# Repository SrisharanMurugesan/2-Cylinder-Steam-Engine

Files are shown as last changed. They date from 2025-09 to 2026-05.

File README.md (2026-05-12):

# 2-Cylinder-Steam-Engine
<p align="center">
  A - Front CAD view
  B - Isometric CAD view
</p>

<p align="center">
  C - Full CAD assembly view
</p>

## Description

A fully engineered, 2-cylinder vertical steam engine designed for assembly.  
This project includes complete CAD models, 3D-printable components, and hardware specs for a working demonstration engine with a shared crankshaft, crosshead guides, and a flywheel mounted on a wooden base.

The design uses standard fasteners and realistic tolerances so that, once printed and cleaned up, the parts assemble with minimal adjustment.

---

### Mechanical Overview

- **Configuration:** Twin vertical cylinders driven by a common crankshaft and flywheel  
- **Structure:** Printed crankcase/block with bolt-on cylinder heads and bearing caps  
- **Motion system:** Pistons → connecting rods → crank → flywheel  
- **Guidance:** Vertical guide rods keep piston rods in pure linear motion  
- **Base:** Wood base plate with mounting points for the engine frame and flywheel bearings  

---

### Tolerances and Fits

The CAD is modeled with 3D-printing realities in mind:

- **Shafts & holes (running fits)**  
  - Shaft diameters: typically 4–6 mm (metal rod recommended)  
  - Printed bearing bores: +0.10 to +0.20 mm over shaft diameter (e.g., 6.10–6.20 mm for a 6 mm shaft)  
- **Fastener holes**  
  - Through holes: +0.20–0.30 mm over screw diameter  
  - Clearance for nuts and heads modeled with +0.20 mm all around  
- **Press-fit features (pins, dowels)**  
  - Undersize the *hole* relative to pin size, then drill to final size as needed  

(If your printer is calibrated and precise, you can tighten these marginal numbers; else use clearances of another 0.05–0.10 mm.)

---

### Recommended Materials

- **Structural parts (block, cylinder, crosshead guides, flywheel):**  
  - PLA+ or PETG  
- **Frictional components (Subject to high friction and constant motion):**  
  - PETG or nylon preferred; PLA will work for demo use  
- **Shafts & pins:**  
  - Steel or brass rod stock (not printed) for better strength and wear

---

### Bambu Lab A1 Print Specs

Optimized slicing settings:

- **Nozzle:** 0.4 mm  
- **Layer height:** 0.16–0.20 mm  
- **Walls/perimeters:** 4  
- **Top/bottom layers:** 6–8  
- **Infill:**
  - Structural parts (block, flywheel, bearing supports): 35–45% gyroid or cubic  
  - Cosmetic/small brackets: 20–25%  
- **Speed:** use A1 “Standard”
- **Supports:**  
  - On build plate only where possible (Supports autogenerated by software will suffice)  
  - Flywheel: printed flat with support only under inner ring if necessary  
- **Brim:** 5–8 mm brim on tall, slender parts (guides, columns)

---

### Notes on Assembly

- Lightly sand all sliding and rotating interfaces.  
- Re-drill critical bores (piston rod guides, main bearing bores, crank pin holes) to their final size.  
- Dry-fit the crankshaft, flywheel, and rods first to ensure rotation before tightening fasteners.  
- A tiny amount of grease or lube on shafts and crossheads will reduce friction significantly.

---

### Authors Note

This steam engine was designed from an old compilation of drawing sheets, which were modeled in SolidWorks to created this engine. I used this engine as a learning marker to learn the fundamentals of automobile design and better develop my skills with SolidWork assemblies. I 3d printed this engine on my Bambu Lab A1 to understand the manufacturing constraints of translating high precision parts into real world products and it currently sits as decoration in my room. I hope you enjoy!

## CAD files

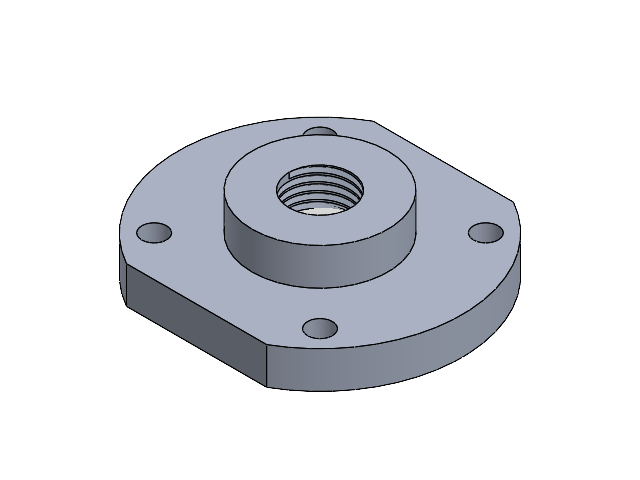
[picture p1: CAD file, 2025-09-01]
SubAssembly/Top Crank.SLDASM
MC2403773CT-001
MC2403774CT-001
MC2403775CT-001

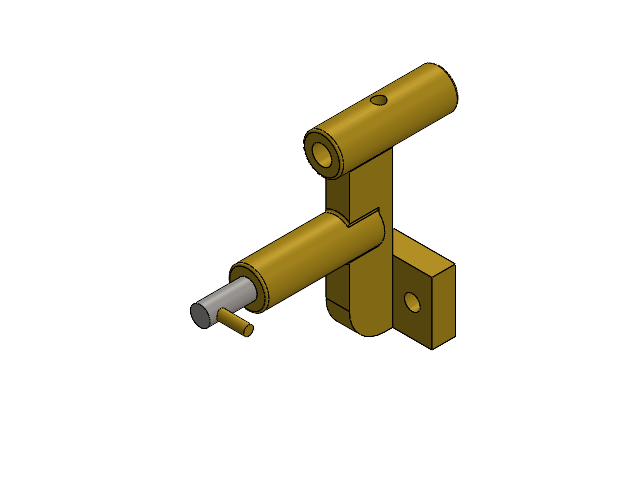
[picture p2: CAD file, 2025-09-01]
SubAssembly/Top Connector.SLDASM
MC2403781CT-001
MC2403782CT-001
MC2403783CT-001

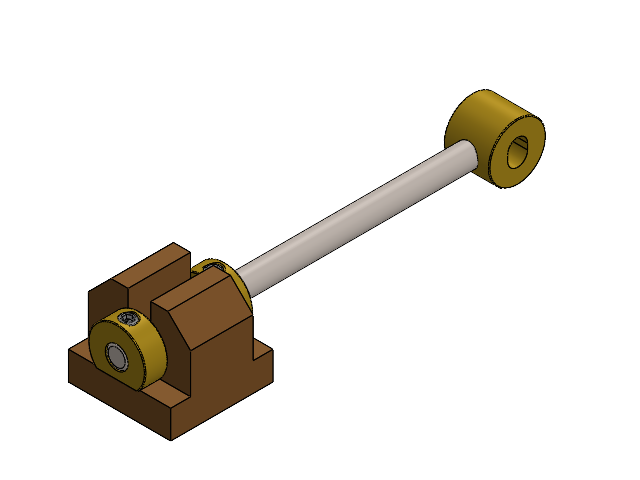
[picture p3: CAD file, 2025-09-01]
SubAssembly/Sub-Assembly4.SLDASM
MC2403729CT-001
MC2403760CT-001
MC2403761CT-001
MC2403731CT-001 x 2

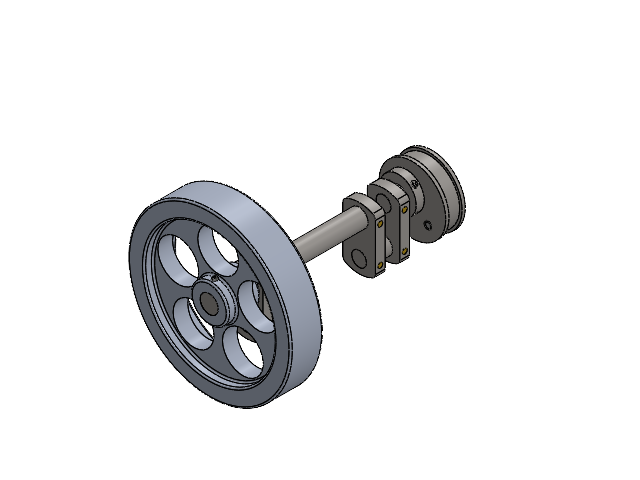
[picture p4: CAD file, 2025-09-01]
SubAssembly/SubAssembly 1.SLDASM
MC2403720CT-001
MC2403758CT-001
MC2403759CT-001
COTS - SCREW R-HEAD A-KEY M4.7X12 92095A192
MC2403724CT-001 x 4
MC2403722CT-001
MC2403723CT-001 x 2
MC2403845CT-001 x 8
MC2403721CT-001 x 2
COTS - SET SCREW M3.0X0.5X6.0 92015A104

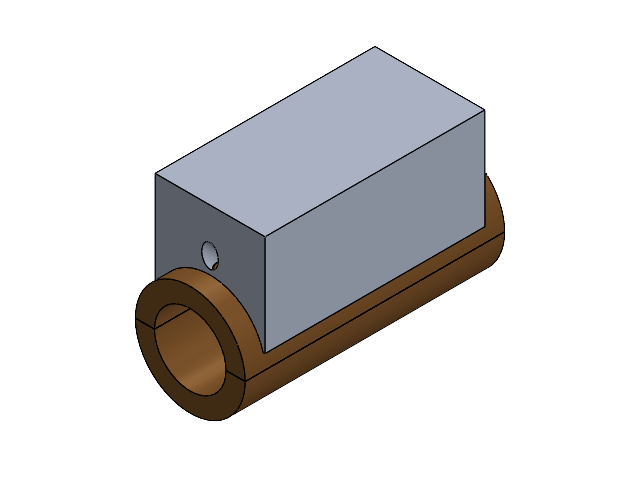
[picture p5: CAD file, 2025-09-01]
SubAssembly/SubAssembly Beginning.SLDASM
MC2403798CT-001
MC2403799CT-001
MC2403800CT-001
MC2403801CT-001

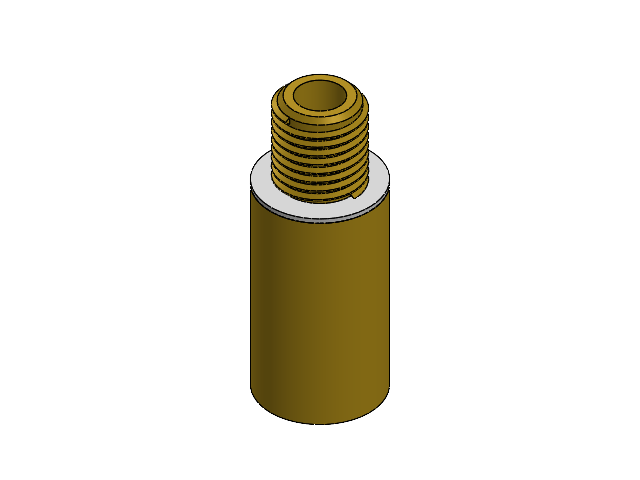
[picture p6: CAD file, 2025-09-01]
SubAssembly/Piston.SLDASM
MC2403771CT-001
MC2403772CT-001

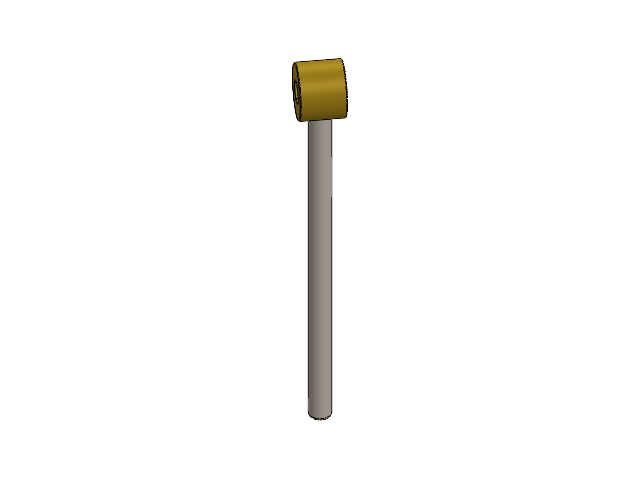
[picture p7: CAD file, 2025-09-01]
SubAssembly/Piston Pipe.SLDASM
MC2403760CT-001
MC2403761CT-001

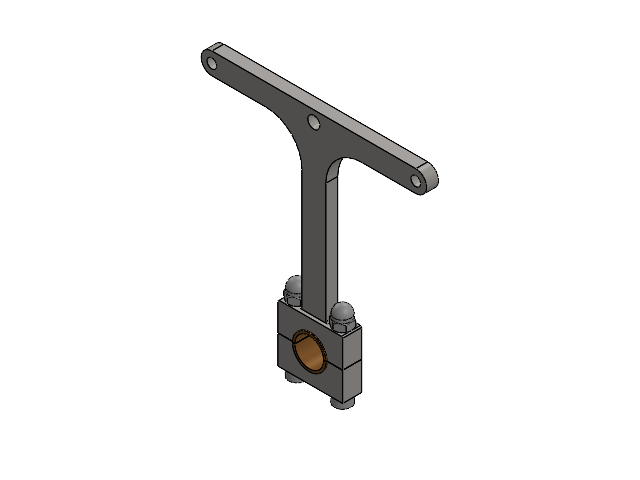
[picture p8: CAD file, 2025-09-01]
SubAssembly/Pipes Connected.SLDASM
MC2403734CT-001
MC2403787CT-001
MC2403849CT-001 x 2

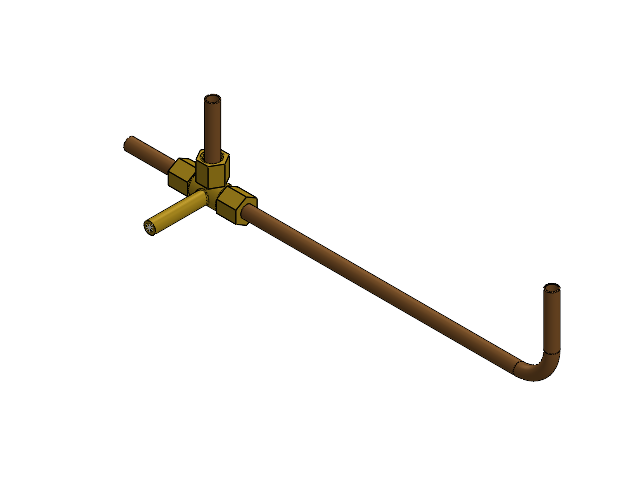
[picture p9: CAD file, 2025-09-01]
SubAssembly/Pipes Beginning.SLDASM
MC2403805CT-001
MC2403806CT-001 x 2
MC2403807CT-001
MC2403784CT-001 x 3
MC2403785CT-001 x 3

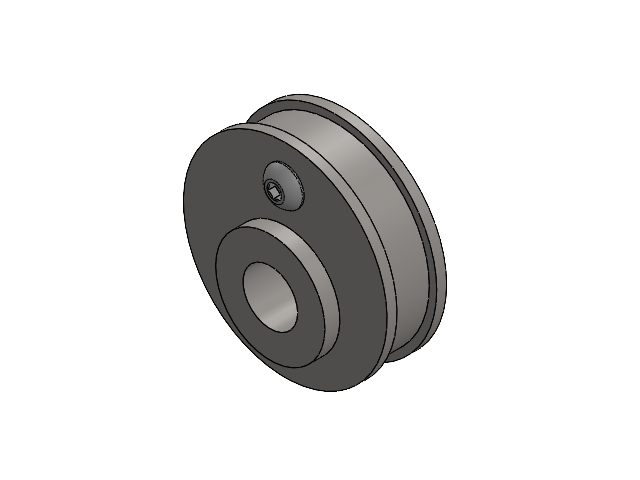
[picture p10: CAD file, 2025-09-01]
SubAssembly/Main Base.SLDASM
MC2403758CT-001
MC2403759CT-001

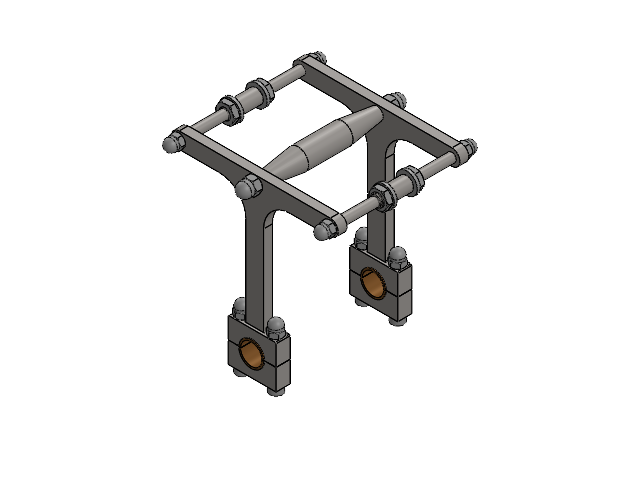
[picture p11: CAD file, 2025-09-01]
SubAssembly/Almost Completed.SLDASM
MC2403735CT-001
MC2403736CT-001 x 2
90326A201_Steel Thin Hex Nut x 4
96505A114_Steel Oversized Washer x 4

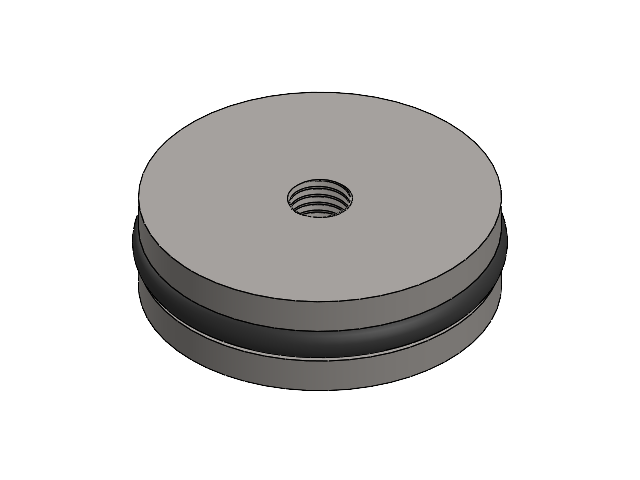
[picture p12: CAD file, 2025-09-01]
SubAssembly/FlyWheel.SLDASM
MC2403786CT-001
COTS - O-RING SILICONE HI TEMP 5233T816

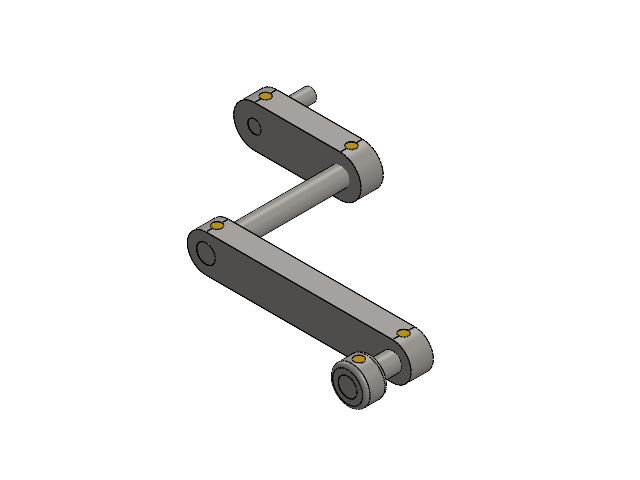
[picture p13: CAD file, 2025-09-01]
SubAssembly/Crank.SLDASM
MC2403762CT-001
MC2403763CT-001
MC2403764CT-001
MC2403716CT-001 x 5
MC2403766CT-001
MC2403767CT-001
MC2403840CT-001

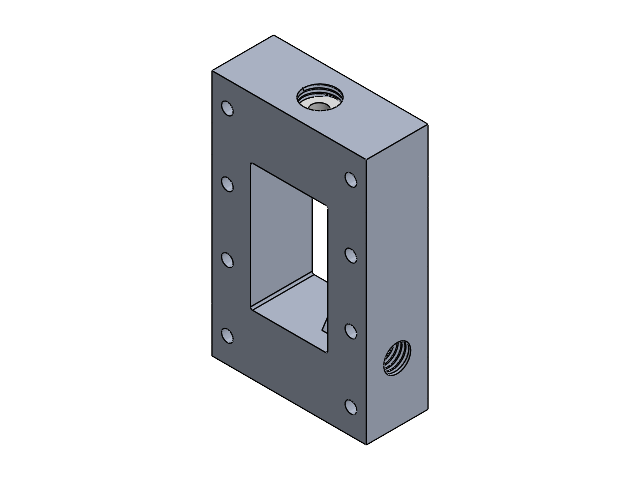
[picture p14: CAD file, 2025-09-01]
SubAssembly/Crank Shaft.SLDASM
MC2403778CT-001
MC2403779CT-001
MC2403780CT-001

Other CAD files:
SubAssembly/Piston Connector.SLDASM
SubAssembly/All pipes connected.SLDASM
SubAssembly/Connected Cranks.SLDASM
SubAssembly/Pipe Conmnector Assembly.SLDASM
Parts/Axel (2).SLDPRT
Parts/Axel (3).SLDPRT
Parts/Axel (4).SLDPRT
Parts/Axel (5).SLDPRT
Parts/Axel (6).SLDPRT
Parts/Axel (7).SLDPRT
Parts/Axel Bridge.SLDPRT
Parts/Axel.SLDPRT
Parts/Base (2).SLDPRT
Parts/Base Join.SLDPRT
Parts/Base Plate (2).SLDPRT
Parts/Base Plate.SLDPRT
Parts/Base.SLDPRT
Parts/Bottom Cover.SLDPRT
Parts/Brass (2).SLDPRT
Parts/Brass .SLDPRT
Parts/Brass Connector.SLDPRT
Parts/Brass Cover.SLDPRT
Parts/Brass Extender.SLDPRT
Parts/Brass.SLDPRT
Parts/COTS - CAP NUT M3X0.5.SLDPRT
Parts/COTS - CAP NUT M4X0.7.SLDPRT
Parts/COTS - CAP NUT M5X0.8.SLDPRT
Parts/COTS - HEX NUT 90685A041.SLDPRT
Parts/COTS - HEX NUT HIGH PROFILE M6.0X1.0 90725A043.SLDPRT
Parts/COTS - O-RING SILICONE HI TEMP 5233T816.SLDPRT
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
